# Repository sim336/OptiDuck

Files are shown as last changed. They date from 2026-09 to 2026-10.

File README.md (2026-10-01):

# OptiDuck

**一台用国产舵机复刻的 Microduck 双足机器人**：主控 Radxa ZERO 3W，执行器换成**飞特 HD-1910 总线舵机**，
步态策略在 MuJoCo / mjlab 里用 PPO 训练，导出 ONNX 后在板子上跑实时推理，
配套一套板端运维服务与 Android 远程运维 App。

这个仓库是**总入口**：它记录整条链路的文档、自研工具链、板端代码与训练侧改动，
上面三块上游代码以 git submodule 引入。

- [部署调试教程.md](docs/Radxa_ZERO_3W_部署调试教程_发布版.md)
- [开发教程.md](docs/Radxa_ZERO_3W_开发教程_发布版.md)

> 本项目是**个人学习 / 复刻项目**，不是产品。所有数据、命令、报错原文都来自这台实机，
> 能复现的写了复现方式，没验完的明确标了「待核实」。详见 [NOTICE.md](NOTICE.md)。

---

## 目录

- [它长什么样](#它长什么样)
- [系统架构](#系统架构)
- [仓库结构](#仓库结构)
- [快速开始](#快速开始)
- [自研工具链：URDF / MJCF 可视化](#自研工具链urdf--mjcf-可视化)
- [板端运维工具](#板端运维工具)
- [实测数据](#实测数据)
- [和上游的关系](#和上游的关系)
- [许可与署名](#许可与署名)
- [大体积数据](#大体积数据)
- [这个项目对应哪些能力](#这个项目对应哪些能力)
- [更新日志](#更新日志)

---

## 它长什么样

### 实机：整机装配完成（2026-10-01）

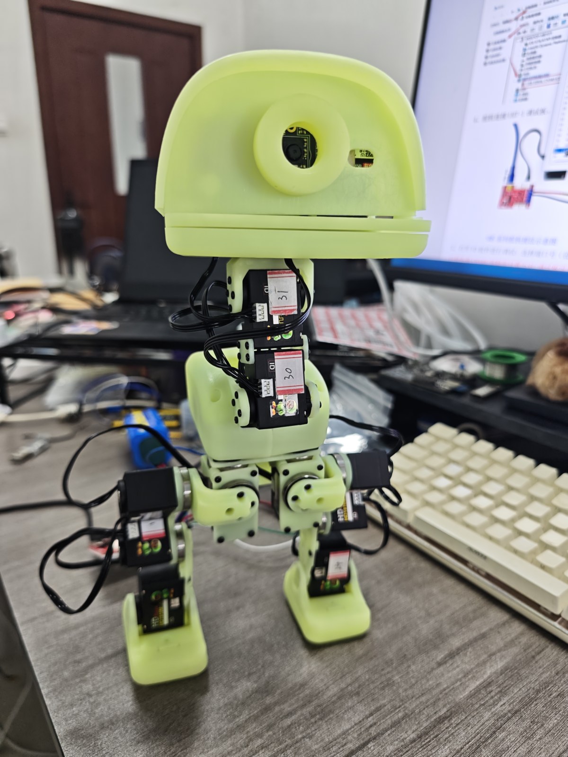
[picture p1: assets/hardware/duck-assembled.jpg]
实机装配完成


薄荷绿色的是打印结构件，黑色的是 15 颗飞特 HD-1910 总线舵机（机身上能看到手写的 ID 标签），
头部开了摄像头孔。装配已完成，能靠两条腿立在桌面上。
这一版还是**裸机状态**：躯干外壳没上、线束没整理，所以图里能看到成把的舵机线和裸露的板子。

### 实机跑策略：起身没站稳就切了走路（2026-10-01）

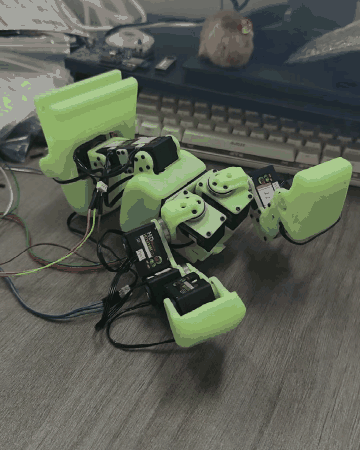
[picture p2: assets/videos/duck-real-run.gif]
实机运行策略


> 动图是 360 px 宽、6 fps 的压缩版；原片 720×1280 / 30 fps / 6.5 s 在
> [`assets/videos/duck-real-run.mp4`](assets/videos/duck-real-run.mp4)。

这是训练出的策略**第一次在真整机上闭环跑起来**的记录，实测结果如实记两条：

- **通过的**：策略确实在板上跑起来了，15 颗舵机按策略输出在动，不是静态摆拍。
- **没通过的**：跑了起身策略，但**没能站稳**，在抖动 / 翻倒的过程中就切去执行走路了 ——
  也就是「起身 → 稳定 → 走路」这三段的状态机衔接还不成立，所以画面里大部分时间
  是机器人在桌面上扑腾，而不是走出去。**这一条不记为「会走了」。**

待排查（都还没有验证，先记下来）：状态机从起身切到走路用的判据是什么（姿态角？计时？），
以及这块板子上当前加载的是哪一批权重。

### 板端：真实开发板上的状态看板

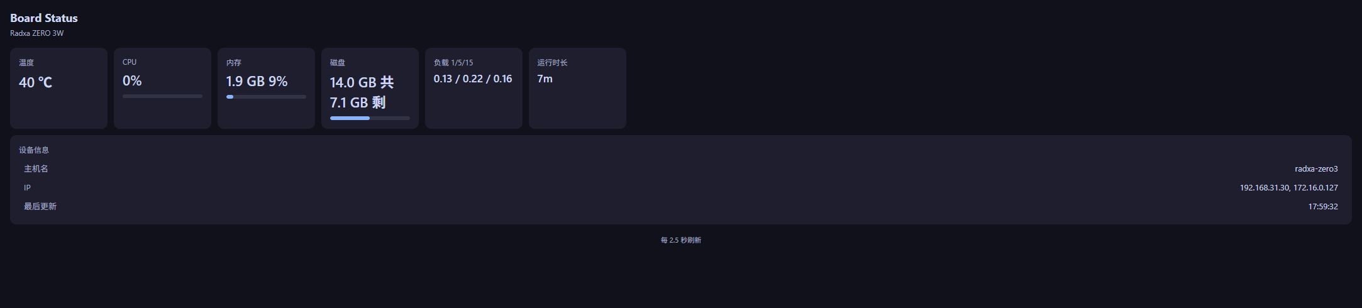
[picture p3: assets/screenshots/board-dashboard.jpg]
板端状态看板


Radxa ZERO 3W 上跑着自研的 Python 状态服务（systemd 托管，端口 8070），
每 2.5 秒刷新温度 / CPU / 内存 / 磁盘 / 负载 / 运行时长。
上图是**这台板子的真实截图**，不是设计稿。

### 训练侧：自研 URDF / MJCF 工具链

三个纯前端（three.js）工具，用来把 SolidWorks 模型转成 MuJoCo 能吃的 MJCF 并肉眼验证：

| 工具 | 干什么 | 截图 |
|---|---|---|
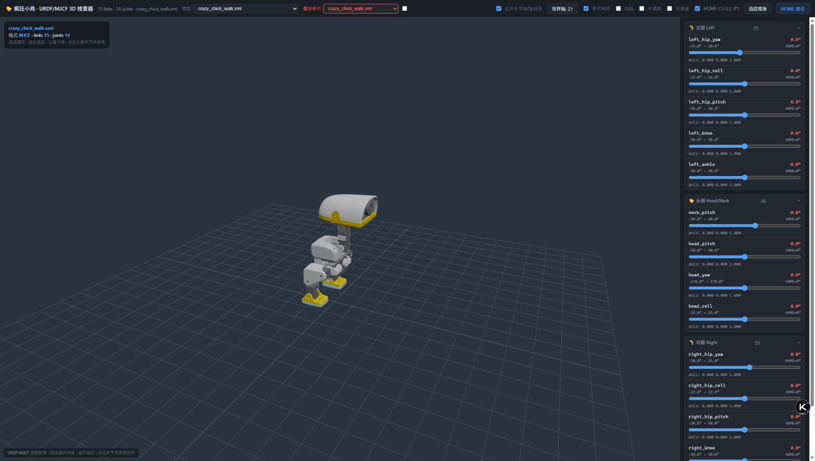
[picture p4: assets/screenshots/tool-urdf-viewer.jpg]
viewer
| **查看器** `viewer/` | 加载 MJCF，实时拖动每个关节的滑块，检查限位、碰撞、网格原点 |  |
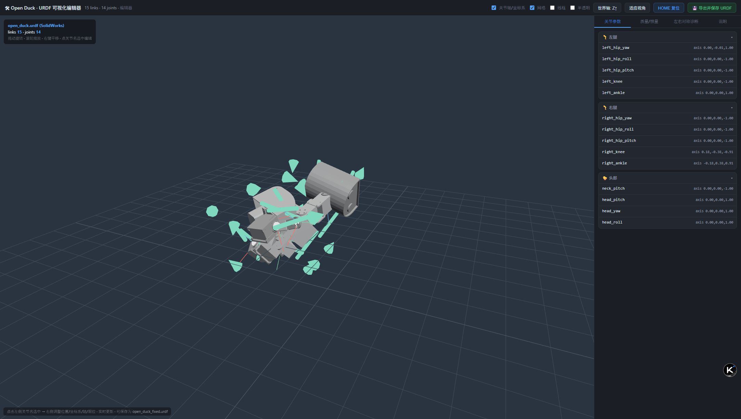
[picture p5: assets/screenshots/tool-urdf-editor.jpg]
editor
| **编辑器** `editor/` | 加载 URDF，改关节 origin / 轴 / 限位、link 质量惯量，左右腿对称诊断，导出修正后的 URDF |  |
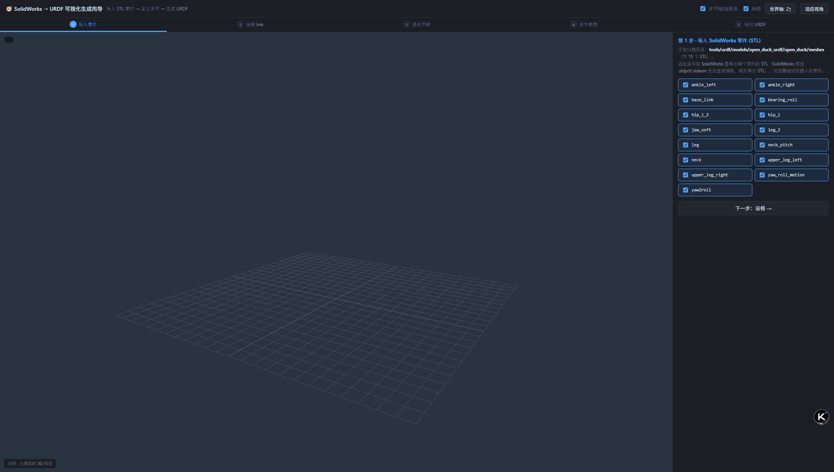
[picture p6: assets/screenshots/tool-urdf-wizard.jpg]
wizard
| **生成向导** `wizard/` | 扫描 STL 零件目录 → 勾选 → 自动生成 URDF 骨架 |  |

还有一个小工具 `mjcf-preview/`：只给 MJCF 的 14 个关节各一个滑块，快速看姿态对不对。

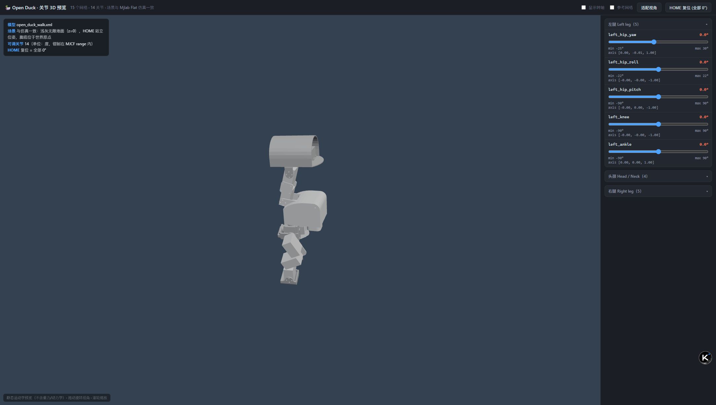
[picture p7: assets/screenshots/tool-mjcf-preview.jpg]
mjcf preview


### 仿真：策略 rollout 渲染帧

下面是 `training/` 里那段 rollout 的逐帧渲染（MuJoCo 离线出图，每 20 帧取一张）：

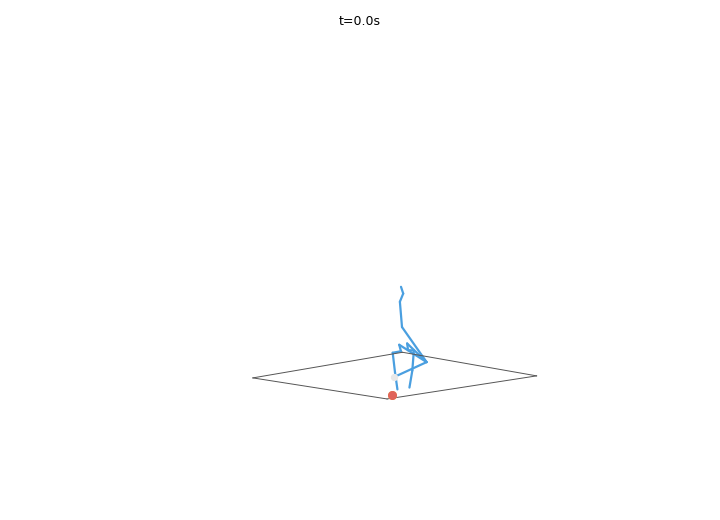
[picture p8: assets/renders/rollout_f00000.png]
rollout

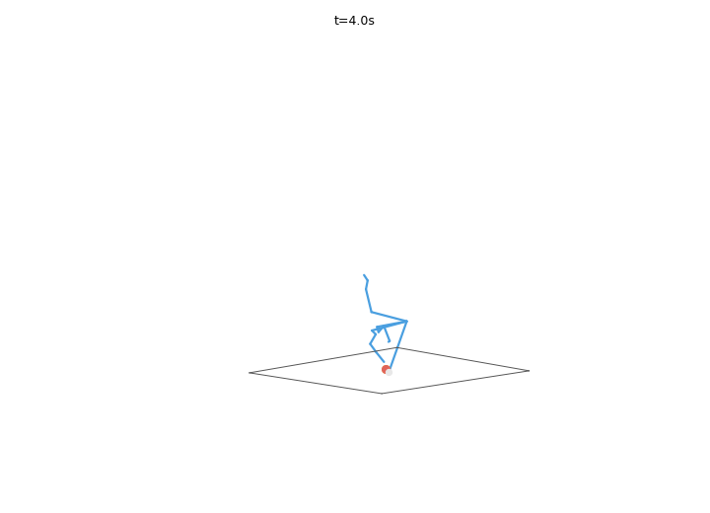
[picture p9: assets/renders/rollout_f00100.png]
rollout

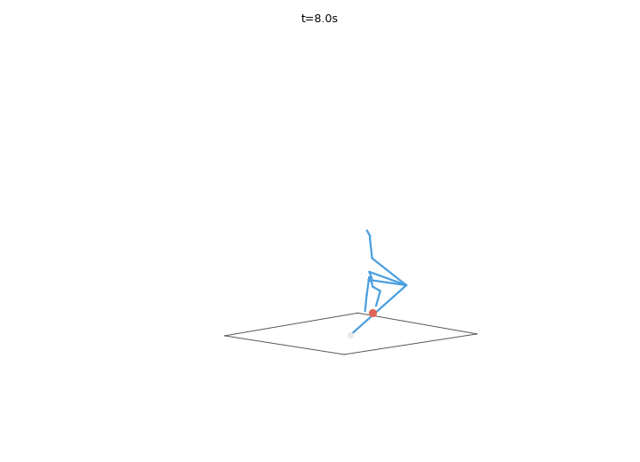
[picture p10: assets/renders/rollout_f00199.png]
rollout


### 移动端：Android 远程运维 App

Kotlin + Jetpack Compose 写的板端运维 App，底部五个页签 —— 连接 / 状态 / 画面 / 功能 / 终端，
支持远程状态告警、**板端摄像头实时画面（MJPEG）**、远程 shell（WebSocket + PTY，带 TAB 补全）与 APK 自更新。

下面四张是 **Android 模拟器里实际运行 App、并真的连上这块板子** 截的图：

| 连接 | 状态 |
|---|---|
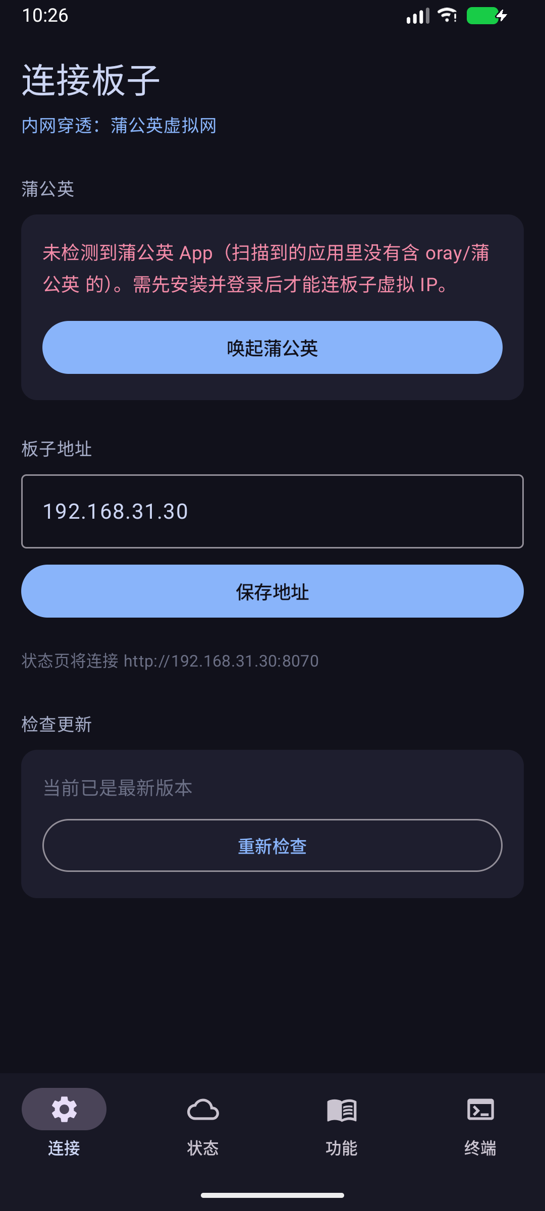
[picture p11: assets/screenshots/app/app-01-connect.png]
app-connect
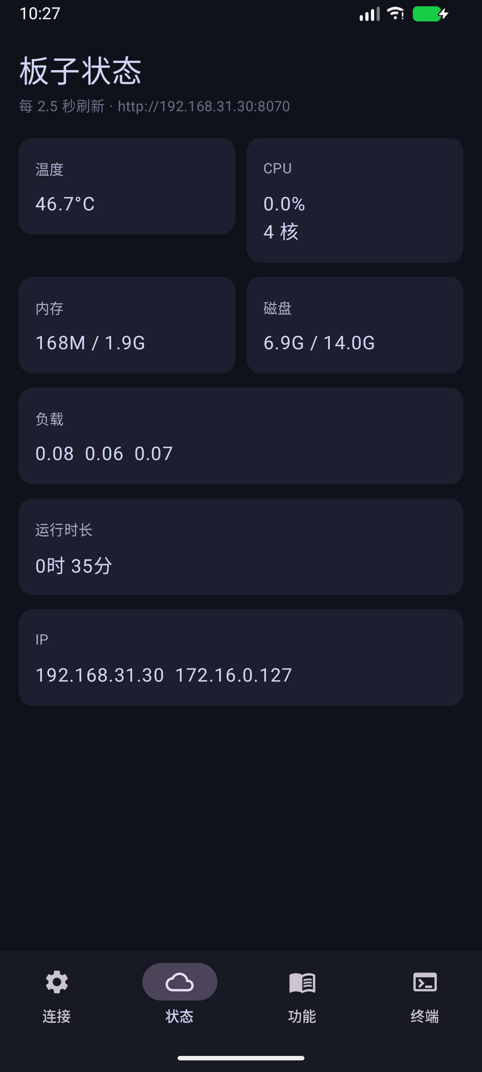
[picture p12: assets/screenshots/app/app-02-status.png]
app-status
|  |  |
| 板子地址、蒲公英检测、APK 自更新入口 | 实时读板上 8070 服务，2.5 s 刷新；图中的温度 / 负载 / IP 都是这台板子的真实值 |

| 功能 | 终端 |
|---|---|
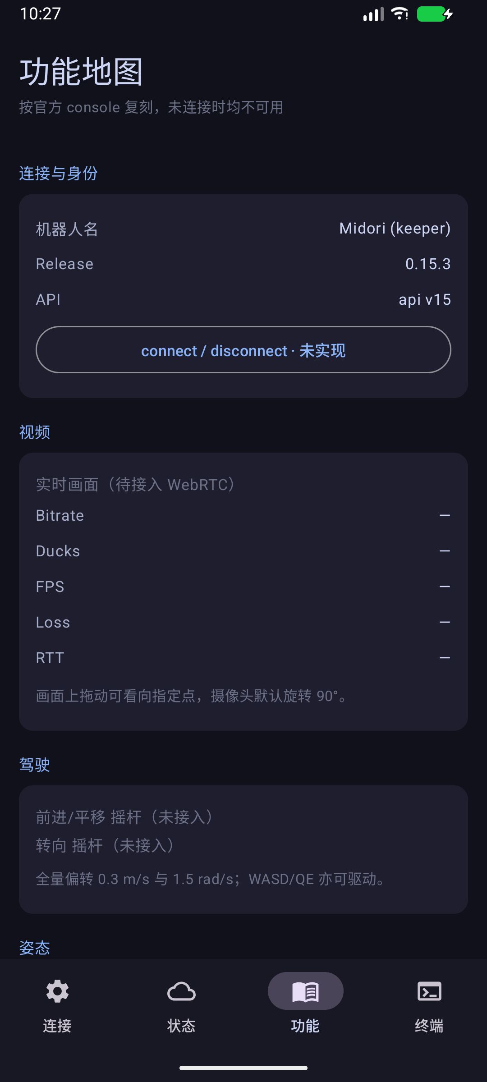
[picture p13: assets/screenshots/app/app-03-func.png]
app-func
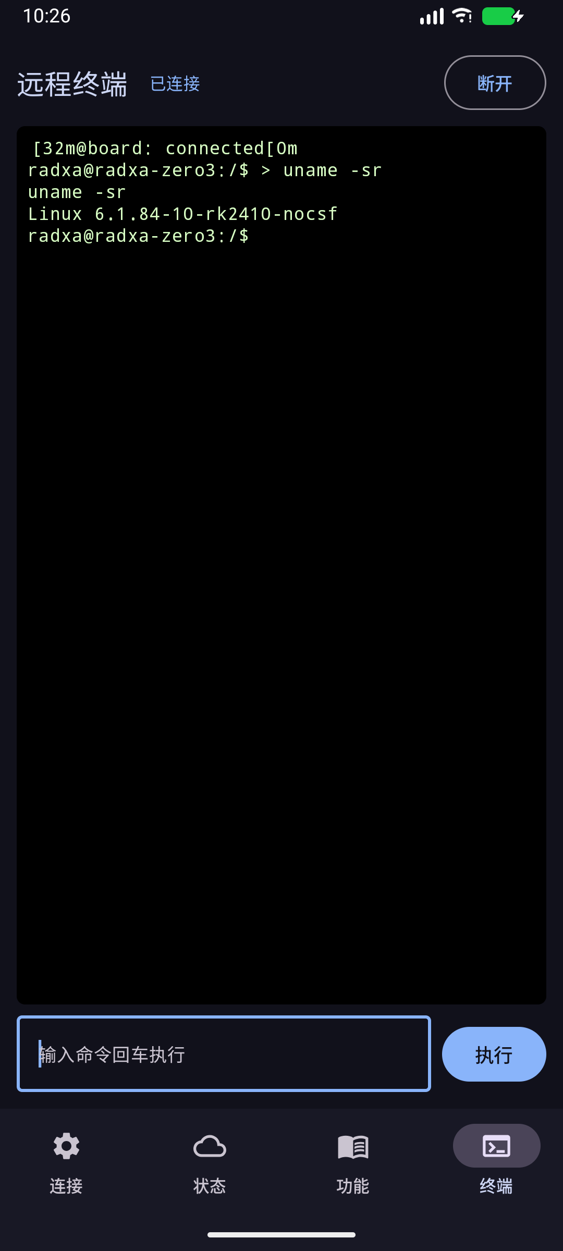
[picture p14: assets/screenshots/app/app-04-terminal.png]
app-terminal
|  |  |
| 按官方 console 复刻的功能地图，未接入的项标为「未实现 / 待接入」 | 远程 shell：首包带 token 鉴权，连上后 `uname -sr` 返回 `Linux 6.1.84-10-rk2410-nocsf` |

> 终端那张图里的输出是**真的从那块板子上取回**的，不是摆拍：
> App 先从 `/api/term` 拿 token，再带 token 连 8071 的 WebSocket，
> 板子侧为每个连接 spawn 一个 PTY bash。协议细节见 [board/report_terminal.py](board/report_terminal.py)。

---

## 系统架构

### 数据通路：仿真 → 板载

```mermaid
flowchart LR
    subgraph PC["开发机（Windows / Linux + CUDA）"]
        A["SolidWorks 整机模型"] --> B["SW2URDF<br/>导出 URDF"]
        B --> C["自研 URDF → MJCF 生成器<br/>重算质量 / 质心 / 惯量"]
        C --> D["MuJoCo 模型<br/>crazy_chick_*.xml"]
        D --> E["mjlab + PPO 训练<br/>走 / 起身 / 坐站"]
        E --> F["checkpoint"]
        F --> G["导出 ONNX"]
    end
    subgraph DEV["实机 / 台架"]
        G -->|"dev-push（交叉编译 + 签名）"| H["Radxa ZERO 3W<br/>robotd / updaterd"]
    end
    G -.->|"policy-rehearsal<br/>CPU 彩排 + 延迟体检"| PC
    H --> I["ONNX Runtime 推理<br/>50 Hz 控制环"]
    I --> J["15 颗 HD-1910 舵机<br/>UART2 总线"]
    I --> K["IMU（I2C4）"]
```

### 板端软件栈

```mermaid
flowchart TB
    subgraph BOARD["Radxa ZERO 3W · Radxa OS (Debian 12) · 6.1 内核"]
        R["robotd<br/>50 Hz 控制环 · 策略执行"] --- C["configd<br/>配置"]
        R --- U["updaterd<br/>OTA 升级 · 签名 · 回滚"]
        R --- BT["btd / padd / tofd<br/>蓝牙 / 触控 / ToF"]
        R --> BUS["舵机总线 /dev/ttyS2"]
        R --> IMU["IMU /dev/i2c-4"]
    end
    subgraph MINE["本项目自研（board/ + app/）"]
        S["robot_status.py<br/>状态服务 :8070"] 
        T["report_terminal.py<br/>WebSocket PTY 终端 :8071"]
    end
    APP["Android App<br/>com.optiduck.board"] -->|"HTTP /api/status"| S
    APP -->|"WebSocket + token"| T
    CLI["robotctl / duckctl"] --> R
```

> 控制环固定 **50 Hz**（20 ms 一拍）。7 个策略槽位名在 Rust 枚举里写死，不能增删改名，
> 只能指向不同的 ONNX 文件或置为 `none`。

---

## 仓库结构

| 路径 | 内容 | 来源 | 许可 |
|---|---|---|---|
| [`docs/`](docs/) | 两本实机教程（部署 / 开发）+ 内部草稿 | 自研 | Apache-2.0 |
| [`tools/`](tools/) | 自研工具链：`urdf/` 三个可视化工具（three.js 零依赖前端）+ 台架标定与遥测（`ft_regs.py` 舵机寄存器直读/直写、`servo_config_gui.py` 逐舵机配置、`bench_mirror.py` 台架实时镜像、`robotd_telemetry_bridge.py` 遥测转发） | 自研 | Apache-2.0 |
| [`board/`](board/) | 板端运维：状态服务、远程终端、画面流、systemd 单元、蒲公英组网脚本 | 自研 | Apache-2.0 |
| [`app/`](app/) | Android 运维 App（Kotlin + Compose） | 自研 | Apache-2.0 |
| [`imu2uart/`](imu2uart/) | STM32F411 固件：IMU → UART 桥（CubeMX 工程）。只入库自研源码与工程文件，vendor 库（`Drivers` 53 MB / `Middlewares`）与 Keil 编译产物可再生产 | 自研 | Apache-2.0 |
| [`training/`](training/) | 在上游 RL 仓里做的改动（补丁 + 改动后的文件） | 派生 | 见 NOTICE |
| [`assets/`](assets/) | 实拍素材与渲染出图：`hardware/` 实机照片、`videos/` 实机运行视频、`screenshots/` 真实截图、`renders/` 仿真渲染帧（**无 AI 生成图**） | 自研 | Apache-2.0 |
| `joyandai/microduck/` | 上板 Rust 软件栈（子模块） | 上游变体 | Apache-2.0 |
| `microduck_rl/` | RL 训练仓（子模块） | 上游变体 | Apache-2.0 |
| `OpenMicroDuck/` | 结构与硬件：CAD / BOM / 渲染图（子模块） | 上游 | **软件 Apache-2.0 / 硬件 CC-BY-NC-SA-4.0** |
| `_scratch_archive/` | 草稿归档：临时脚本、抓取日志、出图 | 自研 | — |

---

## 快速开始

### 一次拉全（含子模块）

```bash
git clone --recurse-submodules git@github.com:sim336/OptiDuck.git
cd OptiDuck
```

已经 clone 过、当时没带子模块：

```bash
git submodule update --init --recursive
```

### 三条链路从哪读起

**① 硬件 / 结构** —— 先看 `OpenMicroDuck/`

- 选型与零件清单：[OpenMicroDuck/docs/bom.md](OpenMicroDuck/docs/bom.md)、[structure.md](OpenMicroDuck/docs/structure.md)
- 舵机适配评审（为什么要换 HD-1910、装配冲突在哪）：[OpenMicroDuck/docs/servo.md](OpenMicroDuck/docs/servo.md)

> ⚠️ `OpenMicroDuck` 的 CAD 与图纸是 **CC-BY-NC-SA-4.0，不可商用**。
> 另有已知的 **BOM 数量分歧**（轴承 ET2216 的数量），下单前请看装配图确认，别直接照抄 BOM。

**② 训练** —— 看 [training/README.md](training/README.md)

它讲清了「哪些是上游的、哪些是我们改的」：新增的 `crazy_chick` MJCF 全套、
两个新任务（`Mjlab-Jump-Flat-CrazyChick` 62D/15D、`Mjlab-Velocity-Flat-OpenDuck` 61D/14D）、
以及为 12 V 供电补的舵机参数。改动以补丁形式给出，可以 `git apply` 回上游仓。

**③ 上板** —— 看两本教程

| 想做什么 | 看哪一节 |
|---|---|
| 先避坑（电源、烧录、Wi-Fi 自动连接） | 部署篇 §0 |
| 烧系统到 SD 卡 / SSH 免密 / headless | 部署篇 §4–§5 |
| 板级 bring-up（舵机总线 `ttyS2` / IMU `i2c4` / 依赖） | 部署篇 §6 |
| 装 `robotd` 等 daemon 软件栈 | 部署篇 §7 |
| 训练 → 导出 ONNX → CPU 彩排 → 发布上板 | 开发篇「模型链路」 |
| 舵机 / IMU / ToF / 摄像头排障 | 开发篇「硬件链路」 |
| 改 Rust 代码一分钟推到板子生效 | 开发篇「代码链路」（`dev-push`） |
| 自己发版 / 用开发签名 | 部署篇 §12 |

- [docs/Radxa_ZERO_3W_部署调试教程_发布版.md](docs/Radxa_ZERO_3W_部署调试教程_发布版.md)
- [docs/Radxa_ZERO_3W_开发教程_发布版.md](docs/Radxa_ZERO_3W_开发教程_发布版.md)

> `docs/internal/` 里是整理前的个人草稿，保留只是为了记录，别当成正式教程读。

**④ 移动端 App** —— 看 [`app/`](app/)

Kotlin + Jetpack Compose，Android Gradle 工程。仓库里**不带** Gradle Wrapper 和 JDK，
用你自己的环境编译即可：

```bash
cd app
# app/local.properties 里写好 sdk.dir=<你的 Android SDK 路径>
gradle assembleDebug          # 产物：app/app/build/outputs/apk/debug/app-debug.apk
adb install -r app/app/build/outputs/apk/debug/app-debug.apk
```

装好后在「连接」页把**板子地址**填成板子的 IP（默认填的是蒲公英虚拟 IP `172.16.0.127`），
状态页就会去读 `<地址>:8070/api/status`，终端页会去 `<地址>:8071` 建 WebSocket。

> ⚠️ Gradle 工程目录是 `app/`，里面的模块目录**也叫** `app/`，所以产物路径是 `app/app/build/...`，
> 不是 `app/build/...`。别找错。

---

## 自研工具链：URDF / MJCF 可视化

三个工具都是**纯前端**（three.js 本地 vendor，无 npm 依赖），靠一个 40 行的 `serve.mjs` 提供静态服务 + 一个保存端点。

### 跑起来

```bash
# 在仓库根目录
node tools/urdf/serve.mjs 8124 .
```

然后打开：

| 地址 | 工具 |
|---|---|
| `http://127.0.0.1:8124/tools/urdf/viewer/` | MJCF 关节查看器 |
| `http://127.0.0.1:8124/tools/urdf/editor/` | URDF 编辑器 |
| `http://127.0.0.1:8124/tools/urdf/wizard/` | SolidWorks → URDF 生成向导 |
| `http://127.0.0.1:8124/tools/urdf/mjcf-preview/` | 14 关节姿态预览 |

> **注意第二个参数**：`serve.mjs` 的根目录必须是**仓库根**，不能是 `tools/urdf/`。
> 因为 viewer 的模型路径写的是仓库内路径（`/microduck_rl/...`、`/training/...`），
> 根目录设错会全部 404。

### 为什么要有这套东西

从 SolidWorks 导出的 URDF 到 MuJoCo 能跑的 MJCF，中间有几件必须肉眼确认的事：

1. **网格原点对不对** —— STL 的原点不在关节轴上，模型就会飞。viewer 拖动关节滑块能立刻看出来。
2. **关节轴向对不对** —— 轴反了，仿真里腿会朝反方向弯。
3. **质量和惯量是不是瞎填的** —— SW2URDF 出来的惯量经常是占位值，要重算。
4. **左右腿是不是对称** —— editor 里有专门的对称诊断。

`wizard/` 解决的是第 1 步之前的脏活：SolidWorks 一次导出几十个 STL，
文件名毫无规律，手工写 URDF 的 `<link>`/`<joint>` 又慢又容易漏。

---

## 板端运维工具

`board/` 里是这台板子上**实际在跑**的东西（不是示例代码）。

| 文件 | 作用 | 板上位置 |
|---|---|---|
| `robot_status.py` | 健康指标 HTTP 服务（端口 8070，返回 `/api/status` JSON） | `/home/radxa/robot_status.py` |
| `index.html` | 状态看板的单页前端（深色卡片，2.5 s 轮询） | `/home/radxa/robot_status_index.html` |
| `report_terminal.py` | WebSocket 远程终端（端口 8071，每次连接 spawn 一个 PTY bash，支持 TAB 补全与颜色） | `/home/radxa/report_terminal.py` |
| `report_video.py` | 摄像头 MJPEG 服务（端口 8072，`/video` 长连接推 640×480@15 的 JPEG；懒启动，无客户端 5 s 自动停流水线，**不经过 mediad**；`/dev/video0` 独占，不能与 mediad 并存） | `/home/radxa/report_video.py` |
| `robot_terminal.py` | 终端侧的辅助脚本 | `/home/radxa/robot_terminal.py` |
| `systemd/robot-status.service` | 状态服务的 systemd 单元 | `/etc/systemd/system/` |
| `systemd/robot-terminal.service` | 终端服务的 systemd 单元 | `/etc/systemd/system/` |
| `systemd/robot-video.service` | 画面服务的 systemd 单元 | `/etc/systemd/system/` |
| `scripts/deploy_status.sh` | 一键部署状态服务到板子 | — |
| `scripts/deploy_video.sh` | 一键部署画面服务到板子（含出流自检） | — |
| `scripts/diag_sudo.sh` | 提权环境诊断 | — |
| `scripts/pgy_*.sh` | 蒲公英（异地组网）客户端的安装 / 登录 / 状态脚本 | — |

### 终端鉴权

终端服务**不能裸露**：每个连接的首包必须带上 token，
token 由板子生成在 `/home/radxa/robot_terminal_token`，
App 先从状态服务的 `/api/term` 拿到端口与 token 再去连。

> ⚠️ **不要把 8071 / 8443 这类端口直接转发到公网。** 这是明确的部署禁忌：
> 一旦暴露，等于把一台能跑 `sudo` 的 shell 送出去。

### 板子上的实况

```
$ robotctl health
robot     degraded: no robot on the motor bus after 99 attempts; is servo power on and the bus wired?
  loop      not measured yet, of 50.0 Hz · 0 ticks · 0 missed
  bus       waiting for a robot to answer, 99 attempts
  imu       not ready

software
  updaterd  0.13.0 (rev 84684db)     units
  robotd    0.13.0 (rev 84684db)       updaterd  active · 0.13.0
  configd   0.13.0 (rev 84684db)       robotd    active · 0.13.0
                                       configd   active · 0.13.0
                                       btd       active · 0.13.0
                                       padd      active · 0.13.0
                                       mediad    stopped
                                       tofd      active · 0.13.0
```

这段是**当前这台板子的真实输出**（照抄，未修饰）。`degraded` 是因为舵机电源此刻没开 ——
`robotd` 上电后要先在总线上找到机器人，找不到就一直重试，这是正常且安全的行为。
`mediad` 是 stopped：**没接摄像头时它会崩溃循环**（找不到 `/dev/media*` 就退出，
systemd 每 ~12 s 拉起一次，每次重扫 GStreamer 插件烧满一核），所以按需再启用。

策略槽位的实况：

```
$ robotctl policy list
mode: walk

   SLOT         ORIGIN     POLICY
   walk         official   velstand.onnx
 * stand        local      /home/radxa/standup_hd1910.onnx
   sitstand     official   alpha_sitstand.onnx
   ground_pick  official   alpha_ground_pick.onnx
   kick_left    official   ball_kick_left.onnx
   kick_right   official   ball_kick_right.onnx
   roulade      official   roulade.onnx
```

`stand` 槽位指向的是**我们自己重训的 HD-1910 起身策略**，其余仍是官方策略。

---

## 实测数据

### 板载 ONNX 推理延迟

在**这台 Radxa ZERO 3W 上**用仓库里编译好的 `policy-rehearsal`（`joyandai/microduck` 的
`duck-control/examples/policy-rehearsal.rs`）跑 1000 步纯推理：

```bash
export ORT_DYLIB_PATH=/usr/local/lib/libonnxruntime.so
./target/release/examples/policy-rehearsal /home/radxa/standup_hd1910.onnx
```

```json
"latency_ms": { "p50": 0.367204, "p95": 0.76124, "p99": 0.836198, "max": 1.069237 },
"over_20_ms": 0,
"scope": "actor inference only; excludes sensor and motor I/O",
"steps": 1000
```

- **p50 ≈ 0.37 ms**，占 50 Hz 控制周期（20 ms）的 **约 1.8%**，p99 也只有 0.84 ms。
- **`over_20_ms: 0`** —— 1000 步里没有一次推理超出控制周期。
- ⚠️ 注意 `scope`：**这只统计 actor 网络推理**，不含读传感器和写舵机的时间。
  拿这个数去论证「整个控制环能跑满 50 Hz」是不严谨的。

### 板子本身

| 项 | 值 |
|---|---|
| 主控 | Radxa ZERO 3W（RK3566 · 2 GB LPDDR4） |
| 系统 | Radxa OS（Debian 12 bookworm），内核 `6.1.84-10-rk2410-nocsf` |
| 舵机 | 飞特 HD-1910-C001 × 15，总线 `/dev/ttyS2`（UART2） |
| 舵机 ID | 左腿 20–24、右腿 10–14、头/颈/嘴 30–34、IMU 200 |
| IMU | I²C-4 |
| 摄像头 | IMX219 8 MP（3280×2464，77° 裸模组） |
| 推理库 | ONNX Runtime 1.28.0（`/usr/local/lib/libonnxruntime.so`） |

> 以上是**逐项 SSH 实测核对过**的值；与网上流传的二手资料不一致的地方（例如
> 舵机总线实测是 I²C4 而某些文档写 I²C3 M0、摄像头 overlay 的启用方式）
> 均已按实机修正，教程里标注了核实状态。

---

## 和上游的关系

`joyandai/microduck` 和 `microduck_rl` **不是干净的上游副本**，而是带本地改动的变体。
为了让以后的合并干净可查，它们都被重新挂到上游历史里最接近的 commit 上，
本地改动各自落成一个独立 commit：

- `joyandai/microduck`：基线 `2c61dcc`（上游 2026-09-02），本地变体 commit `83322b6`
  —— HD-1910 台架 bring-up、IMU 迁到 I2C、舵机总线工具、`source-lessons/` 等 57 个文件。
- `microduck_rl`：上游分支 `develop`，本地改动为 HD-1910 台架 bring-up、BAM 作动器参数、
  `air_time` 奖励调参与碰撞配置拆分；另含 Windows 下的彩排控制改造
  （`infer_policy.py` 用 `msvcrt` 替代 Unix 专属的 `termios`，让彩排能在开发机上直接跑）。
  2026-10-01 又落了 3 个提交：① 供电基准更正到整机 2S（`vin_range` 6.5–8.2、`vin_min` 6.0、
  `forcerange` 0.97 → 1.51 N·m），并补齐 `GROUND_PICK` / `BACKLASH` / `WALK_BACKLASH` 三处
  漏掉的 `USE_HD1910` 判断（含两个新导出的 `robot_openmicroduck_*_backlash.xml`）；
  ② `scene.xml` / `body_server.py` 改指向 OpenMicroDuck 鸭子（此前仿真身体与训练环境不是同一只）；
  ③ velstand 把零指令站立提为一等交付。详见更新日志 v1.02 / v1.03。

这样 `git log` 能直接看出「哪些是上游的、哪些是我们改的」，
`git diff upstream/main` 就是全部本地差异。

### 改动怎么同步（子模块的两步法）

三个代码仓是**独立仓库**，各自提交推送；主仓只记录「指向哪个 commit」。所以一次改动要两步：

```bash
# 第 1 步：在子仓里改、提交、推送
cd microduck_rl
git add -A && git commit -m "..." && git push

# 第 2 步：回主仓更新指针（不能省）
cd ..
git add microduck_rl
git commit -m "bump microduck_rl"
git push
```

第 2 步不能省：别人 clone 主仓时拿到的是主仓里记录的 commit，
你不提交指针，别人就还停在你上次提交的那个版本。

### 合并上游更新

```bash
cd joyandai/microduck
git fetch upstream
git merge upstream/main
```

`microduck_rl` 的上游默认分支是 `develop`。

---

## 许可与署名

| 部分 | 许可 |
|---|---|
| 本仓自有内容（`docs/`、`tools/`、`board/`、`app/`、`imu2uart/`、`assets/`） | **Apache-2.0**（[LICENSE](LICENSE)） |
| `joyandai/microduck`、`microduck_rl` | Apache-2.0 |
| `OpenMicroDuck` 的 CAD / 图纸 / 文档 | **CC-BY-NC-SA-4.0（禁止商用）** |

**完整的分项署名、上游链接与免责声明见 [NOTICE.md](NOTICE.md)。**
商业使用前请务必读一遍 —— `OpenMicroDuck` 那一块是不可商用的。

`assets/` 里**没有任何 AI 生成图片**：`hardware/` 的实机照片与 `videos/` 的运行视频是手机实拍，
`screenshots/` 来自真实浏览器 / Android 模拟器 / 这块开发板，`renders/` 来自 MuJoCo 离线出图。

---

## 大体积数据

以下数据**不在 git 里**（避免仓库膨胀且历史不可撤销），按需作为 Release 附件发布：

| 数据 | 体积 | 说明 |
|---|---|---|
| `hd1910_calibration/` | ~426 MB | HD-1910 舵机台架标定原始 `.log` 轨迹与拟合 `.json` |
| `model_archive/` | ~405 MB | 训练权重归档（sitstand / stand / velocity） |
| `logs/` | ~8 MB | 台架 / 分析 / sysid 原始数据（`bench_*.csv`、`analysis_*.csv`、`sysid_*.md`）。本机工作数据，已加进 `.gitignore`，不作为 Release 附件 |

标定数据拟合后的结果已经浓缩进 `microduck_rl/vendor/bam/bam/params/hd1910/*.json`，
只做仿真训练的话不需要下载原始数据。

---

## 这个项目对应哪些能力

把简历上的项目二拆开到具体产物，方便对照：

| 能力点 | 在本仓的产物 |
|---|---|
| 执行器建模：基于 HD-1910 重绘整机三维模型（SolidWorks） | `OpenMicroDuck/`（CAD / BOM / 结构评审） |
| SW2URDF 导出 + **自研 URDF→MJCF 生成器** | [`tools/urdf/wizard/`](tools/urdf/wizard/)（零件扫描 → URDF）、[`training/microduck_rl/.../crazy_chick/`](training/microduck_rl/src/mjlab_microduck/robot/crazy_chick/)（`make_crazy_chick.py` / `make_open_duck.py`） |
| 重算刚体质量与质心、构建 MuJoCo 仿真模型 | 同上 + [`tools/urdf/viewer/`](tools/urdf/viewer/) 肉眼校验 |
| RL 步态训练（PPO：行走 / 起身 / 坐站） | [`training/README.md`](training/README.md) + `microduck_rl/` 子模块 |
| 针对新舵机增益差异调超参、BAM 作动器辨识 | `microduck_rl/vendor/bam/`、`training/microduck_rl/patches/` |
| Windows 下彩排环境控制（msvcrt 替代 termios） | `microduck_rl/scripts/infer_policy.py` |
| Radxa ZERO 3W 从烧录到 headless 全流程 | [部署调试教程](docs/Radxa_ZERO_3W_部署调试教程_发布版.md) |
| Microduck OTA 升级通道部署与配置 | [开发教程](docs/Radxa_ZERO_3W_开发教程_发布版.md)「代码链路」+ `joyandai/microduck` 的 `updaterd` |
| ONNX 导出 + 板端 ONNX Runtime 推理链路 | [实测数据](#实测数据) 一节（含可复现命令） |
| Python 板端状态服务 + WebSocket 远程终端 | [`board/robot_status.py`](board/robot_status.py)、[`board/report_terminal.py`](board/report_terminal.py) |
| Kotlin/Compose Android App：状态告警 / 远程 shell / APK 自更新 | [`app/`](app/) |
| 跨平台嵌入式开发（C/C++、Python、C#、Kotlin、Rust 周边） | 全仓 |
| ROS / MuJoCo / MATLAB 轨迹规划等工具链经验 | `tools/`（自研可视化）、`microduck_rl`（mjlab + MuJoCo） |

---

## 更新日志

| 版本 | 日期 | 内容 |
|---|---|---|
| **v1.04** | 2026-10-01 | **整机装配完成，策略第一次在真机上跑（附实拍素材）**。<br>① 新增 [`assets/hardware/duck-assembled.jpg`](assets/hardware/duck-assembled.jpg)：15 颗 HD-1910 装到位的整机外观照 —— 打印结构件 + 黑舵机 + 头部摄像头孔，**裸机状态**（躯干外壳未上、线束未整理）。<br>② 新增 [`assets/videos/duck-real-run.gif`](assets/videos/duck-real-run.gif)（README 内嵌动图，360 px / 6 fps / 2.6 MB）与 [`assets/videos/duck-real-run.mp4`](assets/videos/duck-real-run.mp4)（原片 720×1280 / 30 fps / 6.5 s / 0.94 MB）：训练策略第一次在**真整机**上闭环跑的实拍。<br>③ **实测结论 —— 通过项**：策略确实在板上跑起来了，15 颗舵机按策略输出动作。<br>④ **实测结论 —— 未通过项（如实记录，不记为「会走了」）**：跑的是起身策略，但**没站稳**，在抖动 / 翻倒过程中就切去执行走路了 —— 「起身 → 稳定 → 走路」三段的状态机衔接不成立，画面里大部分时间是机器人在桌面上扑腾。<br>⑤ **待排查（均未验证，先留档）**：状态机从起身切到走路的判据是什么（姿态角？计时？）；这块板子上当前加载的是哪一批权重（与 [v1.02](#更新日志) 的供电基准更正 / 仿真·真机饱和率失配是否相关，也还没有证据）。 |
| **v1.03** | 2026-10-01 | **台架工具链、IMU 固件入库，以及 docs 的摄像头记录**。<br>① `tools/` 新增 6 个台架工具（都不是示例代码，是台架上实际在用的）：`ft_regs.py` —— FT-SCS 寄存器直读/直写，起因是 `robot.relax` 报 `torque off`、15 颗舵机全部 ACK 但关节掰不动，绕开 robotd 直读总线后发现 15 颗的 reg40 实测全是 1，那条「已松扭矩」的结论是假的；`servo_config_gui.py` + `servo_progress.json` 逐舵机配置与进度；`bench_mirror.py` 台架只读实时镜像（真机 15 颗 HD-1910 + IMU 映到浏览器 3D，带策略开关与「真·松扭矩」联调按钮）；`robotd_telemetry_bridge.py` 遥测转发；`bench_joint_limits.json` 实测关节限位。<br>② 新增 [`imu2uart/`](imu2uart/) —— STM32F411 的 CubeMX 固件（IMU → UART 桥）。**只收自研源码与工程文件**（`Core/` + `.ioc` + `.mxproject` + Keil 的 `.uvprojx`/`.uvoptx`/`startup`，约 0.2 MB），vendor 库（`Drivers` 53 MB、`Middlewares` 1.3 MB）与 Keil 编译产物（38 MB，另有 7.2 MB `JLinkLog`）全部排除，可由 CubeMX / Keil 再生。<br>③ `logs/` 台架原始数据按仓库既有约定「大体积数据走 Release、不进 git 历史」加入 `.gitignore`。<br>④ `docs/internal` 的零基础教程把摄像头一节从【等硬件】改为【现在能跑】：2026-09-22 已在本机点亮 IMX219（overlay 启用后 probe 成功、`/dev/media0` + `/dev/video0~9` 就位、连续抓流 45 帧 @ 29.96 fps），并更正三处易踩的点 —— Radxa OS 上不用手工编辑 `extlinux.conf`（`u-boot-update` 会把 `/boot/dtbo/` 下所有不带 `.disabled` 的 `.dtbo` 按字母序写进 `fdtoverlays`）；`/boot/dtbo/` 下其实有三个 camera overlay（两个 IMX219 驱动层等价）；别只靠 `dmesg` 验证 —— 它要 sudo，且只证明 sensor probe 成功、不证明链路连通。<br>⑤ `microduck_rl` 另外两个提交：`scene.xml` / `body_server.py` 改指向 OpenMicroDuck 鸭子（此前仿真身体与训练环境不是同一只），velstand 把零指令站立从 25% 侧例提到一等交付（板子上 `stand = "none"`，走路网络是零指令待机的唯一归属者）。 |
| **v1.02** | 2026-10-01 | **训练侧 HD-1910 一致性与供电基准核查（一轮完整审计的落地）**。<br>① **供电基准更正**：训练配置曾按 "5.0 V 稳压轨（4.75–5.25 V）—— NOT 2S" 建模，那个 5 V 是**摆锤台架的桌面电源**，不是整机。整机是 2S 电池、15 个舵机直接挂在电池上（证据：舵机是 4–8.4 V 器件；`duck-control/src/feetech.rs` 写明 "all 15 servos sit on one pack"；robotd 空电关机阈值 6.6 V，若真是 5 V 每次上电都会关机而它从未触发）。改为 `vin_range=(6.5, 8.2)`、`vin_min=6.0`（`microduck_constants.py`）。模型的出力是 `vin × duty_cycle`，所以 5 V 基准会让仿真舵机比真机**弱 1.48 倍**（7.4/5.0）—— 这正是长期存在的仿真/真机饱和率失配（仿真 21% vs 真机 4.2%）的方向与量级；出力由 0.97 N·m 提到 **1.51 N·m**。<br>② **补齐三处漏改**（此前"换执行器只改一处"的说法是错的）：`MICRODUCK_GROUND_PICK_ROBOT_CFG` 与两个 backlash 配置漏了 `USE_HD1910` 判断，会用**官方 XL330 惯量 + HD-1910 执行器参数**的混搭模型；另新导出 `robot_openmicroduck_{walk,groundcontact}_backlash.xml`（`add_backlash.py` 默认 ±1° 背隙，14 个关节，与官方版结构逐项一致、总质量 812.61 g vs 官方 737.24 g）。rollers 两个配置仍为**已知缺口**，原因写在 `microduck_constants.py` 注释里（OpenMicroDuck 没有带轮子的 CAD 导出）。`publish/manifest.py` 的 `robot.servos` 由 `xl330` 更正为 `hd1910`（该字段在 `docs/policy-manifest.md` 里属 display 字段，daemon 只校验 `robot.model`）。<br>③ **参数归属澄清**：`kt = 0.692 N·m/A` 是**台架空载恒速法实测**（R²=0.998，n=24，6 档转速正反两向各两条），不是规格书值；规格书 0.7358 高约 6%，被独立方法（静态保持法 `kt/R ∈ [0.16, 0.23]`）交叉验证。`kp_fw = 32` 是**真机 reg50 回读**（不是 XL330 的 200，用 200 会硬约 6 倍）。<br>④ **文档更正**：`hd1910_README.md` 全文停留在标定前（描述 `hd1910_m6.json`、kp_fw 200、max_current 1.75、复用 xl330 骨架），已加"已过时"标注 + 估算值/现行值对照表，并保留仍然有效的规格书推导；`mae_report_kpfix.md` 标注为已过时的中间快照（权威记录是 `characterization.json`）；`characterization.json` 的 `supply_voltage_V: 5.0` 与 `note_supply` 标注作废（**数值一字未改**）。<br>⑤ **新增一个已知的显示级不一致**（未改，留档）：`bam/feetech/actuator.py` 的便捷属性 `self.kt = 0.7358` 是规格书默认值，而生效值是模型 JSON 覆盖后的 `model.kt = 0.692`——控制律用的始终是后者，故不影响物理，只可能误导日志读数；`kd` 的 sim 0.346（拟合，`d_scale=4.0`）与真机 reg51 的寄存器值 40 不是同一单位，勿直接对比。 |
| **v1.01** | 2026-09-22 | **App 打通实时画面（自建 MJPEG，全程不经 mediad）**。① 板端新增 [`board/report_video.py`](board/report_video.py)：GStreamer `v4l2src ! videorate ! videoconvert ! jpegenc ! appsink` 直接抓 `/dev/video0`，以 `multipart/x-mixed-replace` 推流（端口 8072），首包带 token（复用 `/home/radxa/robot_terminal_token`），流水线**懒启动、无客户端 5 s 自动停**，另有 `/snapshot` 单帧与 `/stats` 自检端点；② App 底部导航扩为 **5 个页签**（连接 / 状态 / 画面 / 功能 / 终端，App 版本 2.1.0 → 2.2.0、versionCode 5），新增 [`VideoScreen.kt`](app/app/src/main/java/com/optiduck/board/VideoScreen.kt) 按 SOI/EOI 切帧、逐帧解码上屏，并显示分辨率 / 帧率 / 累计帧 / 单帧大小；功能地图的「视频」区块从占位改为跳转「画面」页，WebRTC 那套指标（bitrate / loss / RTT）明确标注仍未接入；③ **实测**（板子本机 curl 拉流）：4 s 收 **58 帧 ≈ 14.5 fps**、单帧 ≈ **20 KB**（约 2.3 Mbps）、`/snapshot` 落盘为合规 640×480 baseline JPEG 且画面可辨实物（天花板灯管 + 纸箱），无 token 一律 401、无客户端 5 s 后 `/stats` 回到 `running: false`；④ **CPU 实测**（占单核）：无客户端、流水线已停时 **0.0%**，1 个客户端推 640×480@15 时 **≈16%**（≈ 整机 4%），推流期间板子 loadavg 0.11 → 0.51、温度 50.6 → 51.2 °C 基本不动 —— 所以**「连接 / 断开」本身就是开关，默认关，不连时板上零占用**，未再加额外总闸；⑤ 两个坑：PyGObject **不暴露** `GstAppSink.pull_sample` / `try_pull_sample`（GIR 注记把它们隐藏了），只能用 `new-sample` 信号 + `sink.emit("pull-sample")` 取帧；**`/dev/video0` 是独占设备**，第二个抓流进程直接报 `Device '/dev/video0' is busy`，即本服务与官方 mediad / WebRTC **互斥不能并存**。 |
| **v1.00** | 2026-09-19 | 仓库整体整理为开源项目形态：<br>① 目录重构 —— 教程归 `docs/`、URDF 工具链归 `tools/`、板端运维归 `board/`、Android App 归 `app/`、训练改动归 `training/`、截图与渲染归 `assets/`；<br>② 补齐 `LICENSE`（Apache-2.0）、`NOTICE.md`（分项署名与上游许可）、`.gitignore`；<br>③ 新增真实截图墙（板端看板 / 三个 URDF 工具 / MJCF 预览 / App 四页，均为实际运行截图）；<br>④ 修复状态看板「磁盘」卡片把字节数直接显示的 bug（改为 `xx.x GB 共 xx.x GB 剩`）；<br>⑤ 修复搬迁后工具链的模型路径（viewer / editor / wizard 全部指向仓内路径），并把 `serve.mjs` 的根目录用法写进文档；<br>⑥ 实测并记录板载 ONNX 推理延迟（p50 0.367 ms / 1000 步 / `over_20_ms: 0`）；<br>⑦ App 端到端联调：重新编译 debug APK 装进模拟器，实测「状态页读到板上真实指标 + 终端 WebSocket 带 token 连上并执行 `uname -sr`」，截图与结论一并入库。 |

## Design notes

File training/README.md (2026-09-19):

# training/ · 强化学习训练侧的改动

这里放的是**在别人开源仓库里做的改动**（补丁 + 改动后的文件），用于溯源：
哪些是上游的，哪些是本项目自己加的。

训练本身需要在装了 CUDA 的机器上跑 mjlab + MuJoCo，本目录**不是可直接运行的训练仓**，
它是「改动集」——把它应用回上游仓才能跑。

---

## 一、两个上游仓与本地改动

| 子目录 | 上游仓库 | 本地改动性质 |
|---|---|---|
| `microduck_rl/` | [pollen-robotics/microduck_rl](https://github.com/pollen-robotics/microduck_rl)（`develop` 分支） | 4 个官方文件被改写 + 一套新增的 `crazy_chick` 模型与任务 |
| `Open_Duck_Playground/` | [apirrone/Open_Duck_Playground](https://github.com/apirrone/Open_Duck_Playground)（`main` 分支） | 1 处：给 MJCF 补 `sts3215_12v` 执行器类 |

---

## 二、目录结构

```
training/
├── microduck_rl/
│   ├── patches/
│   │   └── tracked_changes.patch            ← 4 个官方文件的 diff，可直接 git apply
│   ├── scripts/                             ← 新增：冒烟 / 渲染 / 实时可视化脚本
│   │   ├── live_open_duck.py
│   │   ├── render_open_duck_rollout.py
│   │   ├── smoke_crazy_chick.py
│   │   └── smoke_open_duck.py
│   ├── src/mjlab_microduck/
│   │   ├── actuator/friction_dr_bam.py      ← 修改版
│   │   ├── robot/crazy_chick/               ← ★ 自研：MJCF / 常量 / 生成器 / 网格
│   │   │   ├── crazy_chick_*.xml            （walk / allcollisions / 各 backlash 变体）
│   │   │   ├── open_duck_walk.xml           （SolidWorks 形态）
│   │   │   ├── make_crazy_chick.py / make_open_duck.py
│   │   │   ├── assets/params_sts3215_m6.json
│   │   │   └── open_duck_assets/*.STL
│   │   └── tasks/
│   │       ├── microduck_jump_env_cfg.py        ← ★ 新增任务（62D 观测 / 15D 动作）
│   │       ├── microduck_open_duck_env_cfg.py   ← ★ 新增任务（61D / 14D，velocity）
│   │       ├── microduck_roller_standup_env_cfg.py  ← 修改版（关节索引修正）
│   │       └── __init__.py                      ← 修改版（注册新任务）
│   └── tests/test_roller_standup_cfg.py     ← 修改版（配套索引测试）
│
└── Open_Duck_Playground/
    ├── patches/0001-12v-parameters.patch
    └── playground/open_duck_mini_v2/xmls/open_duck_mini_v2_backlash.xml
```

---

## 三、改了哪些、为什么

### 1. `actuator/friction_dr_bam.py` —— 修一个 AttributeError

`FrictionDRBamActuator.initialize()` 里缺了 `q_target_smooth` 的初始化，
走 mjlab 这条路径时会抛 `AttributeError`。补上即可，不影响 BAM 的辨识语义。

### 2. `tasks/__init__.py` —— 注册两个新任务

- `Mjlab-Jump-Flat-CrazyChick` —— 跳跃任务，**62 维观测 / 15 维动作**
- `Mjlab-Velocity-Flat-OpenDuck` —— 速度跟踪任务，**61 维观测 / 14 维动作**（SolidWorks 导出形态）

> 观测/动作维度是**硬契约**：训出来的 ONNX 输入输出必须和板端 `robotd` 期望的维度一致，
> 维度不对会在上板推理时直接报错。

### 3. `microduck_roller_standup_env_cfg.py` —— 修 CUDA 越界

`_LEG_JOINTS` / `_NECK_JOINTS` 用的还是「16 个舵机」的索引，但滚轮关节被 `passive_` 过滤掉之后
实际只剩 14 个，索引会越界。改成 14 舵机视图的 0–13 后正常。

### 4. `robot/crazy_chick/` —— 整套自研仿真模型

从 SolidWorks 结构件导出、重算质心与惯量后生成的 MJCF，包含：

- `crazy_chick_walk.xml` 系列 —— 走步任务用
- `*_allcollisions*.xml` —— 打开全部碰撞体（含滚轮变体），用于排查自碰撞
- `*_backlash*.xml` —— 带**齿隙/回差**建模的变体（舵机减速箱回差是 sim2real 的主要 gap 之一）
- `open_duck_walk.xml` —— SolidWorks 形态的 Open Duck，配套 `open_duck_assets/` 网格

配套的 `assets/params_sts3215_m6.json` 是 STS3215 舵机的作动器参数。

### 5. `Open_Duck_Playground/…/open_duck_mini_v2_backlash.xml` —— 12 V 参数

上游默认按 7.4 V 的舵机特性给的增益与限幅。换 12 V 供电后阻尼、摩擦损耗、armature、
kp、力范围都要跟着改，于是新增了一个 `sts3215_12v` 执行器类，并把各关节的
`class="sts3215"` 改为 `class="chosen_actuator"`。

---

## 四、怎么把改动放回上游仓

> 前提：上游仓已经 pull 到与本目录记录时相同的基线；若上游又更新过，应用补丁可能冲突，
> 冲突时请以 `patches/*.patch` 为准人工合并。

### microduck_rl

```bash
git clone https://github.com/pollen-robotics/microduck_rl.git
cd microduck_rl
git checkout develop

# 1) 应用对官方文件的修改
git apply /path/to/OptiDuck/training/microduck_rl/patches/tracked_changes.patch

# 2) 复制新增文件（保持相对路径）
cp -r /path/to/OptiDuck/training/microduck_rl/src/mjlab_microduck/robot/crazy_chick  src/mjlab_microduck/robot/
cp    /path/to/OptiDuck/training/microduck_rl/src/mjlab_microduck/tasks/*.py       src/mjlab_microduck/tasks/
cp    /path/to/OptiDuck/training/microduck_rl/scripts/*.py                          scripts/
cp    /path/to/OptiDuck/training/microduck_rl/tests/test_roller_standup_cfg.py      tests/
```

### Open_Duck_Playground

```bash
git clone https://github.com/apirrone/Open_Duck_Playground.git
cd Open_Duck_Playground
git apply /path/to/OptiDuck/training/Open_Duck_Playground/patches/0001-12v-parameters.patch
```

---

## 五、和 `microduck_rl` 子模块的关系

主仓根目录的 `microduck_rl/` 是**子模块**（可编译、可跑训练的那份）；
本目录的 `training/microduck_rl/` 是**改动集**（小而全，方便看懂与复用）。

两者内容有重叠但不完全等同：子模块里还包含 HD1910 台架标定数据、BAM 参数、
训练权重归档等大体积内容，那些走 Release 发布，不在这里。

---

## 六、许可

见仓库根目录 [NOTICE.md](../NOTICE.md) §3。
`microduck_rl` 为 Apache-2.0；`Open_Duck_Playground` 上游未声明许可证文件，
此处仅作学习记录保留，再分发前请与原作者确认。

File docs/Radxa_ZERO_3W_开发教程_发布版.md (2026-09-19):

# Radxa ZERO 3W 机器人开发实战：模型训练、上板部署与 Rust 开发

**摘要**：本文承接《[Radxa_ZERO_3W_部署调试教程_发布版.md](./Radxa_ZERO_3W_部署调试教程_发布版.md)》，讲的是"把软件装上之后"的事 —— 自己训练一个策略模型、导出并部署到 Radxa ZERO 3W 上、调试舵机与各类传感器、改一行 Rust 代码并在一分钟内推到板子生效。全文覆盖三条链路：**模型链路**（训练 → 导出 ONNX → CPU 彩排 → 发布/占槽 → 上板）、**硬件链路**（舵机总线、IMU、ToF、摄像头的体检与排障）、**代码链路**（`dev-push` 的交叉编译、签名、健康门与回滚）。文中所有命令、寄存器值、版本号、报错原文与判定阈值均来自实机记录，可直接照做。**前置条件**：已按部署篇把板子配好（能 SSH、`robotctl` 已装、7 个守护进程在跑），并具备 Linux 命令行、SSH、PowerShell 的基本使用能力，对强化学习（PPO）与 Rust 有初步了解。文末附常见问题速查表、参考资料索引、参考来源、待核实事项与更新日志。

**图例说明**（全文只用这一套标记）：

| 标记 | 含义 |
| ---- | ---- |
| **【无需硬件】** | 不接舵机 / 传感器也能做完 |
| **【需硬件】** | 必须硬件就绪（舵机、摄像头、ToF HAT 等）才可执行 |
| **【原理】** | 解释性内容，赶时间可跳过 |
| **⚠️** | 已知的坑、或容易失败的地方 |

> **关于路径**：下文出现的 `~/microduck`（上板软件栈仓库）、`~/microduck_rl`（强化学习训练仓库）以及 `~/OpenMicroDuck`（硬件资料仓库）都是**示例路径**，请替换为你自己的本地工作目录；出现 `C:\Users\<你的用户名>` 的地方同理。出现 `<板子IP>` 的地方，替换为板子的局域网地址。本教程使用的参考板为 Radxa ZERO 3W（RK3566 / 2GB LPDDR4 / 无 eMMC），实测数据见各节标注 —— **不同批次的板子可能不同，请以自己板子的实测为准**。

## 本文目录

- [0. 开篇：路线图与三个仓库](#0-开篇路线图与三个仓库)
  - [0.1 三条链路与心智模型](#01-三条链路与心智模型)
  - [0.2 三个仓库、一个外部分发站](#02-三个仓库一个外部分发站)
- [1. 先建立全局观：这个系统是怎么长在一起的](#1-先建立全局观这个系统是怎么长在一起的)
  - [1.1 一张图认识 7 个守护进程](#11-一张图认识-7-个守护进程)
  - [1.2 两个必须分清的词：`slot` 与 `skill`、`policy` 与 `detector`](#12-两个必须分清的词slot-与-skillpolicy-与-detector)
  - [1.3 三条更新通道：什么走哪条，为什么](#13-三条更新通道什么走哪条为什么)
  - [1.4 三板斧（先记住，后面反复用）](#14-三板斧先记住后面反复用)
- [2. 模型部署：从训练到上板（全链路）](#2-模型部署从训练到上板全链路)
  - [2.1 训练一个走路策略（最短路径）](#21-训练一个走路策略最短路径)
  - [2.2 导出 ONNX（归一化会被烤进模型）](#22-导出-onnx归一化会被烤进模型)
  - [2.3 CPU 彩排：上真机前的最后一次检查](#23-cpu-彩排上真机前的最后一次检查)
  - [2.4 发布到 HF Hub：一个模型变成一个"仓库"](#24-发布到-hf-hub一个模型变成一个仓库)
  - [2.5 策略上板：五条命令全场景](#25-策略上板五条命令全场景)
  - [2.6 检测器模型：另一条链（YOLO → RKNN）](#26-检测器模型另一条链yolo--rknn)
  - [2.7 NPU 推理链路：模型在板子上到底怎么跑](#27-npu-推理链路模型在板子上到底怎么跑)
  - [2.8 两条模型链路对照表](#28-两条模型链路对照表)
- [3. 硬件调试：从体检到动起来](#3-硬件调试从体检到动起来)
  - [3.0 硬件地图：这条鸭子身上有什么](#30-硬件地图这条鸭子身上有什么)
  - [3.0.1 舵机选型：HD1910 与官方 XL330](#301-舵机选型hd1910-与官方-xl330)
  - [3.0.2 采购清单：硬件到手前先对一遍（OpenMicroDuck BOM）](#302-采购清单硬件到手前先对一遍openmicroduck-bom)
  - [3.1 硬件体检【无需硬件】：先养成这个习惯](#31-硬件体检无需硬件先养成这个习惯)
  - [3.2 舵机总线调试【需硬件】：Dynamixel 链](#32-舵机总线调试需硬件dynamixel-链)
  - [3.3 IMU【需硬件】：姿势的裁判](#33-imu需硬件姿势的裁判)
  - [3.4 ToF【需硬件】：HAT 上的 8×8 深度矩阵](#34-tof需硬件hat-上的-88-深度矩阵)
  - [3.5 摄像头【需硬件】：看世界的眼睛](#35-摄像头需硬件看世界的眼睛)
  - [3.6 音频【需硬件】：一句话带过](#36-音频需硬件一句话带过)
  - [3.7 常见硬件故障速查表](#37-常见硬件故障速查表)
- [4. 软件开发：改代码，推到板子上](#4-软件开发改代码推到板子上)
  - [4.1 代码结构：一个 workspace，七个 daemon](#41-代码结构一个-workspace七个-daemon)
  - [4.2 一次性准备（只在第一台板子做一次）](#42-一次性准备只在第一台板子做一次)
  - [4.3 dev-push 闭环：改一行 → 板子上看到它](#43-dev-push-闭环改一行--板子上看到它)
  - [4.4 第一个真实改动：加一条"被摸"日志](#44-第一个真实改动加一条被摸日志)
  - [4.5 示例项目：spaces/ 里有什么](#45-示例项目spaces-里有什么)
  - [4.6 调试三板斧（按顺序用）](#46-调试三板斧按顺序用)
  - [4.7 dev-push 常见错误速查](#47-dev-push-常见错误速查)
- [5. 端到端演练：给鸭子加一个"被摸会回应"的行为](#5-端到端演练给鸭子加一个被摸会回应的行为)
- [6. 常见问题速查](#6-常见问题速查)
- [7. 参考资料索引（按主题）](#7-参考资料索引按主题)
- [参考来源](#参考来源)
- [待核实事项](#待核实事项)
- [更新日志](#更新日志)

---

## 0. 开篇：路线图与三个仓库

这一节先给出全局图景：三条链路各自解决什么问题，以及手上有哪几个代码仓库。**建议在动手前先通读一遍**，后面每一节都能对回这张图。

### 0.1 三条链路与心智模型

三条链路在本文各占一节：

```mermaid
flowchart LR
  subgraph M["模型链路 §2"]
    M1["训练 PPO<br/>microduck_rl"] --> M2["导出 ONNX<br/>scripts/export.py"] --> M3["转 RKNN<br/>检测器<br/>to_rknn.py"] --> M4["发布到 HF Hub<br/>policies /<br/>duck-detector"]
  end
  subgraph C["代码链路 §4"]
    C1["改代码"] --> C2["交叉编译"] --> C3["dev-push.sh<br/>打包 + 签名 + apply + 健康门"]
  end
  subgraph H["硬件链路 §3"]
    H1["robotctl<br/>health / monitor"]
    H2["舵机 · IMU · ToF · 摄像头"]
  end
  M4 -->|updaterd| N1["/opt/robot/policies/current<br/>/opt/robot/detector/current"]
  C3 --> N2["/opt/robot/daemon/current<br/>release 版本"]
  N1 --> N3["robotd<br/>50 Hz 控制循环"]
  N2 --> N3
  N3 --> H2
  H1 -.->|观测| N3
```

> **图 0**：三条链路各自的起点与终点 —— 模型与代码都是"往上送"（送到板子的 `current` 符号链接），硬件则是被 `robotd` 驱动、被 `robotctl` 观测的对象。三条链路的关系在这里一眼可见，后面每节都能对回这张图。

一句话版本：

- **模型 = 被动数据**（`.onnx` / `.rknn` + `manifest.json`），走 **HF Hub → updaterd** 通道，更新**不重启 daemon 之外的任何东西**，随时可以回退；
- **代码 = 主动逻辑**（Rust 二进制 + 板级脚本），走 **dev-push / release** 通道，每次替换都要过**签名校验 + 健康门 + 自动回滚**；
- **硬件 = 被调试的对象**，全部以 `robotctl health` / `monitor` 为观测入口。

> 💡 **部署篇讲"装"，本篇讲"造"。** 部署篇里出现过的 `policies/current → seed-v5`、`detector/current → seed-duck-v1` 这两个符号链接，就是模型链路的终点 —— 读完 §2 你会知道它们是怎么被填上的、以及如何填上自己的模型。

### 0.2 三个仓库、一个外部分发站

**三块代码、三个仓库**，先建立这个概念：

| 仓库 | 示例本地路径 | 干什么 |
| ---- | ---- | ---- |
| `microduck` | `~/microduck` | **上板软件栈**：7 个 Rust daemon、`robotctl`/`duckctl`、板级脚本。开发主要在这里 |
| `microduck_rl` | `~/microduck_rl` | **强化学习训练**：MuJoCo + PPO 训走路/站立/翻跟头，导出 ONNX |
| `duck_detector`（外部） | 在 GitHub / HF 上 | **检测器训练**：YOLO 模型训练 + ONNX→RKNN 转换（不在本地仓库里） |

还有一个"仓库"不是代码：**Hugging Face Hub**。策略（`microduck-*`）、检测器（`microduck-duck-detector`）都以"文件 + 一个 `manifest.json`"的形式发布在 HF 上，板子通过 `updaterd` 从 HF 拉取。**模型和策略的更新不经过 daemon 发版** —— 这是全篇最重要的概念之一。

对新手而言，先分清这份教程的阅读路线：

| 想做什么 | 读哪节 |
| ---- | ---- |
| 先搞清楚"鸭子系统到底怎么长在一起的" | §1 |
| 训练 / 部署一个自己的策略或检测模型 | §2（全链路） |
| 调舵机、IMU、ToF、摄像头 | §3 |
| 改 Rust 代码并推到板子上跑 | §4 |
| 把上面串起来做一个完整小功能 | §5（端到端演练） |

> 训练链路用到 `uv`（一个包与命令管理器，可为每条命令单独创建隔离环境，速度快、兼容性好）；代码链路用到 Rust 工具链与 `cargo`。这些工具的具体安装方法在各节分别给出。

## 1. 先建立全局观：这个系统是怎么长在一起的

### 1.1 一张图认识 7 个守护进程

部署篇只讲"如何装上"，没有说明它们各自是什么。这里补充（来自 `docs/design/architecture.md`）：

```mermaid
flowchart LR
  subgraph CORE["JSON-RPC 2.0 · 一行的 NDJSON · unix socket"]
    R1["robotd（50 Hz 控制循环，唯一能碰电机的人）"]
    R2["configd（Wi-Fi/名字/配对）"]
    R3["tofd（ToF 8×8 深度矩阵，只发不收）"]
  end

  E1["手柄"] -->|"BLE"| P1["padd"]
  E2["手机"] -->|"BLE"| P2["btd"]
  E3["SSH（robotctl）"] -->|"ssh"| P3["robotctl"]
  E4["远端"] -->|"WebRTC"| P4["mediad"]
  E5["GitHub release"] -->|"https"| P5["updaterd"]

  P1 --> CORE
  P2 --> CORE
  P3 --> CORE
  P4 --> CORE
  P5 --> CORE

  CORE -->|"一条 Dynamixel UART（/dev/ttyS2）"| M1["15 个舵机 + IMU（id 200，本教程参考板使用的 HD1910）"]
```

> **图 1**：7 个守护进程与外部入口的关系——外部入口经 unix socket 接入板内的 `robotd` / `configd` / `tofd`，再由 `robotd` 通过一条 Dynamixel UART 驱动舵机与 IMU。

**三个必须记住的硬规则**（后面调试全靠它们）：

1. **`robotd` 是唯一能命令电机的人。** 其他进程只能发"意图"（走多快、看哪里、站起来），安全性由 `robotd` 裁决。所以舵机总线出问题，先怀疑 `robotd`。
2. **`configd` / `updaterd` / `btd` 不依赖 `robotd`。** 机器人控制循环挂掉时，仍可改 Wi-Fi、更新、回滚——这是"永不砖"的根基。
3. **服务和数据分两条路：** 命令/状态走 unix socket JSON-RPC（控制面），视频/音频帧**绝不**走 socket（数据面）。所以"摄像头画面卡了"和"电机不动了"永远是两个问题。

### 1.2 两个必须分清的词：`slot` 与 `skill`、`policy` 与 `detector`

| 词 | 意思 | 例子 |
| --- | --- | --- |
| **slot（槽位）** | 机器人**默认**跑什么：7 个固定槽位 `walk`/`stand`/`sitstand`/`ground_pick`/`kick_left`/`kick_right`/`roulade` | `walk` 槽装走路步态 |
| **skill（技能）** | 机器人**被要求时**跑什么：一次性的动作，跑完自己回去 | 鞠躬`polite-bow`、前滚翻 `roulade` |
| **policy（策略）** | 从 RL 训练出的`obs[1,61] → actions[1,14]` 的 ONNX 模型 | `walk.onnx` |
| **detector（检测器）** | 从图像训练出的目标检测模型（YOLO），输入 320×320 帧，输出 2100 个候选框 | `duck_detect.rknn`（NPU）/ `.onnx`（CPU 兜底） |

```text
robotctl policy list   # 看 7 个槽位 + 已装的 skills
robotctl policy add polite-bow <HF repo>   # 加一个技能
robotctl robot do polite-bow               # 让它跑一下
```

> 💡 **`slot` 由配置指向某个模型文件，`skill` 由名字被调用。** 一个策略文件放对地方（槽位/技能），就是"部署"的全部。

### 1.3 三条更新通道：什么走哪条，为什么

| 更新内容 | 通道 | 门槛 | 失败后果 |
| --- | --- | --- | --- |
| **策略 / 检测器模型** | HF Hub →`updaterd`（`robotctl policy update` / `robotctl duck-detector update`） | 只需`manifest.json` 字段合法 | 拒绝安装，现有模型不动 |
| **daemon 代码（发版）** | GitHub release →`robotctl update apply daemon` | 签名 + 健康门 | 自动回滚到上一个 release |
| **你的开发代码** | `dev-push.sh`（用开发密钥签名）→`robotctl update apply --from` | 开发板 + dev key | 同上，自动回滚 |

**为什么模型单独一条通道？** 因为"换一个策略"和"换一个 daemon"是两种风险等级：
策略文件是数据，`robotd` 每次加载前都会校验形状（`obs_len`/`action_len`/`model_api`/`robot.model`），
错了顶多拒绝加载；而 daemon 二进制是代码，错了可能让板子失联，所以必须过签名 + 健康门 + 回滚。
记住这个分层，后面所有操作都不迷路。

### 1.4 三板斧（先记住，后面反复用）

```bash
robotctl version          # 每个 daemon 实际跑的版本 vs 已安装版本（先跑这个，别信记忆）
robotctl health           # 硬件 + 软件一份报告；不健康时退出码非 0（可接脚本）
robotctl monitor          # 实时：指令 vs 实际、IMU 重力、循环频率、电量和温度
```

`robotctl monitor` 是调试主力，先记几个键：`q` 退出、`t` 打开 ToF 矩阵、`c` 打开摄像头、
`d` 关掉右侧机器人小图、`p` 打开手柄输入流。终端不够宽时按 `d` 关掉机器人图。

## 2. 模型部署：从训练到上板（全链路）

> 目标：本节结束后，可以把一个**自己训出来的模型**（或仓库里已有的模型）放到鸭子上跑起来，
> 并知道每一步卡住时去哪查。全链路五段：

```mermaid
flowchart LR
  A1["① 训练（microduck_rl）：uv run train"] --> A2["② 导出 ONNX：export.py"]
  A2 --> A3["③ 彩排（CPU）：infer_policy / policy-rehearsal"]
  A3 -.->|"可选分叉：要叫名字 / 绑手柄 / 分享"| A4["④ 发布到 HF Hub：uv run publish"]
  A3 -->|"只在自己板子上用（local 来源）"| A5["⑤ 上板占槽 / 发布：robotctl policy / duck-detector"]
  A4 --> A5
  A5 --> A6["板子上生效"]
```

> **图 2**：从训练到板子上生效的完整链路，其中"④ 发布到 HF Hub"是可选的虚线分叉。

**④ 的取舍**是：自己板子上用 → 跳过 ④，ONNX 拷到板子直接占槽位（local 来源）；要叫名字/绑手柄/分享 → 先 ④（`uv run publish`），再装成技能。

策略和检测器是**两条平行的链**（训练仓不同、转换不同、上板命令不同），分开讲，最后汇总一张对照表。（uv 是一个包及命令管理器，可以为每个命令单独创建环境运行，速度快、兼容性好）

### 2.1 训练一个走路策略（最短路径）

训练仓是 `microduck_rl`，基于 mjlab（MuJoCo + Warp）跑 PPO（rsl_rl）。

mjlab：一个物理机器学习模型，用来分配及观测每次**PyTorch**的结果。一次训练迭代流程如下

1. > **mjlab 重置并并行运行数千个仿真环境**
   > 基于 MuJoCo Warp，在 GPU 上批量步进物理世界。
   >
2. > **策略网络（PyTorch）接收观测，输出动作**
   > 观测是 PyTorch 张量，策略网络也是 PyTorch `nn.Module`，两者共享 GPU 内存，零拷贝。
   >
3. > **mjlab 把动作送入物理引擎，计算新观测和奖励**
   > 奖励、终止条件、课程学习、域随机化都由 mjlab 定义。
   >
4. > **RSL-RL 等算法层用 PyTorch 计算损失和梯度**
   > mjlab 收集 rollout 数据，RSL-RL 调用 PyTorch 的 `autograd` 和 `optimizer` 更新策略参数。
   >
5. > **循环直到策略收敛**
   > mjlab 负责“跑环境”，PyTorch 负责“学参数”。
   >

**第一目标是跑通冒烟测试**，不是训出好策略——冒烟测试 1–2 分钟，能拦下约 95% 的配置错误
（这是 `microduck_rl/AGENTS.md` 的原话：*Never launch a long run without one*）。

```bash
cd ~/microduck_rl

# 0) 先同步依赖（uv 管理，装好 uv 后）
uv sync

# 1) 冒烟测试（必须先跑；64 envs × 5 iterations，1–2 分钟）
uv run train Mjlab-Velocity-Flat-MicroDuck --env.scene.num-envs 64 --agent.max_iterations 5

# 2) 正式训练（需要 CUDA GPU；8–12 GB 显存用 1024 envs，≥16 GB 用 4096）
uv run train Mjlab-Velocity-Flat-MicroDuck \
  --env.scene.num-envs 1024 \
  --agent.max_iterations 15000

# 3) 续训（从某个 checkpoint 接着跑）
uv run train Mjlab-Velocity-Flat-MicroDuck \
  --env.scene.num-envs 1024 \
  --agent.load-checkpoint logs/rsl_rl/velocity/<run>/model_15000.pt \
  --agent.resume True \
  --agent.max_iterations 30000
```

来源：`docs/training_config_velocity_hd1910.md` §10 训练命令、`microduck_rl/AGENTS.md` Commands。

**训练产物**：`logs/rsl_rl/velocity/<timestamp>/model_<iter>.pt`；
曲线在 wandb 项目 `mjlab_microduck`（本地跑是离线 run：`wandb/offline-run-*`）。

#### 训练前必须懂的三件事（否则训出来的东西上不了板）

**① 观测是 61 维，全系统共享，别动它。** 布局固定：`48 维本体感受 + 13 维命令块 [twist(3), head_pose(4), body_pose(6)]`，顺序固定。新任务只改命令块的含义，**不能删槽位**
（AGENTS.md Invariants 第一条）。全零命令 = 站立——这是部署时的空闲状态，必须显式训练过。

**② 关节布局是 14 个舵机**，`ctrl idx = joint idx`：

```text
0–4   左腿：hip_yaw, hip_roll, hip_pitch, knee, ankle
5–8   脖子/头：neck_pitch, head_pitch, head_yaw, head_roll
9–13  右腿
```

**MDP** 是 **Markov Decision Process** 的缩写，中文叫  **马尔可夫决策过程** 。它是强化学习里描述“智能体如何在一系列状态下做决策”的数学框架。

写 MDP 时永远用 `_servo_joint_ids` / `_servo_joint_pos` 辅助函数取关节下标，
**不要硬编码**（换带被动关节的模型时下标会错位）。

**③ 执行器是 BAM 模型**（电压控制的作动器，摩擦力由执行器自己算）。电机参数按型号分开存：
`microduck_rl/vendor/bam/bam/params/hd1910/*.json`（本教程参考板使用的型号）/ `hls2909`（另一款）。
训练、彩排命令都要带对应 `--motor hd1910`（§2.3）。`dof_frictionloss` 在 BAM 下是零——
给关节摩擦加 DR **（Domain Randomization，域随机化）**要缩放执行器的 `friction_scale`，否则是静默的无效操作。
**为什么按型号分开？因为换执行器 = 重训策略**：官方 XL330 的 ONNX 是给 XL330 的 BAM M6
执行器模型训的，直接换到 HD1910 上不能 bit-exact 复用（OpenMicroDuck `docs/servo.md` §1），
电机型号写在训练/彩排命令里（`--motor hd1910`），从源头就锁对执行器参数。

#### 训练纪律（少走几个月的弯路）

- **奖励符号：** `microduck_mdp` 里自取负的惩罚项（`*_penalty` / `*_l1` 返回 ≤ 0）要用**正权重**，
  否则双重取负变成"奖励违规"。铁律：每个 `Episode_Reward/<penalty>` 在 wandb 里必须 ≤ 0。
- **预算参考：** 简单一次性动作 ≈ 1000 iterations（4096 envs）；走路等复杂步态 4000–6000。
- **失败先测再改：** 别凭感觉调奖励，先 headless 评估 checkpoint，很多"失败"只是 checkpoint 太早。

> 💡 **当前板子实况：** 板子上 `policies/current → seed-v5` 是官方策略集。训练的第一步
> 不是替换它，而是先在 PC 上跑通"冒烟 → 导出 → 彩排"，等 §2.3 的彩排通过再谈上板。

### 2.2 导出 ONNX（归一化会被烤进模型）

训练完的 checkpoint 不能直接用，必须走**官方导出器**——它会把观测归一化
（`obs_normalization=True`）**烘焙进 ONNX**。手工转换会丢掉归一化，在仿真里玩看不出问题
（play 时环境会再归一化一次），上了真机才露馅。这是 AGENTS.md 明确警告过的坑。

```bash
# 方式 A：从 wandb run 导出
uv run scripts/export.py Mjlab-Velocity-Flat-MicroDuck --wandb-run-path <entity/project/run_id>

# 方式 B：从本地 checkpoint 导出（最常用）
uv run scripts/export.py Mjlab-Velocity-Flat-MicroDuck \
  --onnx-file walk_hd1910.onnx --checkpoint <iter>
```

例如需要导出以下目录中的模型：`~/microduck_rl/logs/rsl_rl/velocity/2026-09-15_20-44-58_prebom_resume`

实际命令为：

```Shell
# 1) 切到训练仓库根目录（导出器按相对路径找 logs/）
cd ~/microduck_rl

# 2) 导出 model_7750.pt → walk_hd1910.onnx（归一化自动烤进 ONNX）
uv run scripts/export.py Mjlab-Velocity-Flat-MicroDuck `
  --checkpoint-file "~/microduck_rl/logs/rsl_rl/velocity/2026-09-15_20-44-58_prebom_resume/model_7750.pt" `
  --onnx-file walk_hd1910.onnx

# 3) 确认产物（应显示 walk_hd1910.onnx，约几十 MB）
Get-ChildItem walk_hd1910.onnx | Select-Object Name, Length, LastWriteTime
```

3D演示模型的命令如下：

```Shell
cd ~/microduck_rl

uv run play Mjlab-Velocity-Flat-MicroDuck `
  --checkpoint-file "~/microduck_rl/logs/rsl_rl/velocity/2026-09-15_20-44-58_prebom_resume/model_7750.pt" `
  --num-envs 1
```

导出实现（`microduck_rl/src/mjlab_microduck/export.py` L251-L269）的核心动作：
`runner.export_policy_to_onnx` 只导出 actor（critic 不上板），把观测归一化的均值/方差写成
ONNX 常量，并把 `model_api`、`obs_len`、`action_len` 等写进 metadata。

**产出契约**（也是板子校验的契约，见 `docs/recurrent-policies.md` 与 `docs/policy-manifest.md`）：

| | 输入 | 输出 |
| --- | --- | --- |
| 前馈模型 | `obs [1, 61]` | `actions [1, 14]` |
| LSTM 模型（`model_api: 2`） | `obs [1, 61]`, `h_in`, `c_in` | `actions [1, 14]`, `h_out`, `c_out` |

所有张量 float32、按名字匹配（与顺序无关）。**LSTM 导出必须标 `model_api: 2`**，
老 daemon 会拒绝安装；前馈是 API 1。

### 2.3 CPU 彩排：上真机前的最后一次检查

彩排解决两个不同的问题，用的是两个不同的工具（**以下命令是 linux 环境**）：

| 彩排 | 在哪跑 | 回答什么问题 | 工具 |
| --- | --- | --- | --- |
| ① 训练仓彩排 | 开发机 MuJoCo 仿真 | 策略动作合不合理？能不能走/站/起身？ | `infer_policy.py`  |
| ② 上板仓彩排 | **板子上**、生产 Rust 推理路径 | 板子跑不跑得动？延迟够不够 50 Hz？ | `policy-rehearsal` |

**两者都要做，顺序不能换**：先在训练仓看动作（行为对不对），再去上板仓测延迟（性能够不够）。
下面分开讲。多数人会栽在②的一个认知上，先看②。

```mermaid
flowchart TD
  S0["CPU 彩排：上真机前的最后一次检查"] --> S1["① 训练仓彩排 — 看动作对不对（开发机 MuJoCo 仿真，infer_policy.py）"]
  S1 --> D1{"动作合不合理？能不能走 / 站 / 起身？"}
  D1 -->|"否"| F1["回到训练 / 导出（§2.1、§2.2）"]
  D1 -->|"是"| S2["② 上板仓彩排 — 测延迟（板子上跑 policy-rehearsal）"]
  S2 --> D2{"p95 / p99 / max 稳在 20 ms 内，over_20_ms 为 0？"}
  D2 -->|"否"| F2["不能上板：延迟超标，先排查"]
  D2 -->|"是"| F3["通过彩排，进入 §2.4 发布"]
```

> **图 3**：两条彩排子路径及其判定——先看动作（行为对不对），再测延迟（性能够不够），顺序不能换。

#### 2.3.1 训练仓彩排：看动作对不对（仿真）

在训练仓 `microduck_rl` 里，用 MuJoCo + 真实执行器参数（默认已是 hd1910 电机模型）把策略跑一遍：

```bash
# 训练仓（microduck_rl）目录下
uv run scripts/infer_policy.py --walking walk_hd1910.onnx --motor hd1910
```

它会弹出一个 3D 查看器，可用方向键驱动它，直观确认策略行为正常。
这一步**只验证动作合理性，测不了延迟**——仿真机比板子快，仿真时间不代表板上时间。

> 💡 前一步 §2.2 的"3D 演示"也是类似的目的（`uv run play ...`），但它加载的是 checkpoint，
> 而这里加载的是**导出后的 ONNX**——观测归一化已经烘焙进去，行为应当一致。以 ONNX 的结果为准。

#### 2.3.2 上板仓彩排：测延迟（板子跑不跑得动）

**⚠️ 摆正认知：这条彩排必须在板子上跑，不是在开发机上。**
官方文档（`docs/recurrent-policies.md` §Offline rehearsal）写得很明确：
"Run the built example **on the Radxa** to establish onboard timing;
development-host timings do not establish the robot's timing budget."
开发机的 CPU 比板子快得多，拿开发机的 p50 去判断"能不能跑 50Hz"，
等于拿 i9 的帧率给手机做性能预算。**板子的耗时才是真预算。**

彩排目标：确认策略在 **50 Hz 控制环**（每步预算 20 ms）下，推理延迟不超标。
注意这个时间**只算 actor 推理**，不含传感器读取、电机写入和调度开销。

完整步骤如下：

**第 1 步：确认模型是官方导出器导出的**（§2.2 已做）

`uv run scripts/export.py` 把观测归一化**烘焙进 ONNX**，并写入 `model_api`/`obs_len`/
`action_len` 等 metadata。手工转换丢归一化，仿真里看不出问题，上了真机才露馅。
上板前先看一眼维数契约（在开发机的 Python REPL 或 venv 里跑）：

```python
import onnx
m = onnx.load("standup_hd1910.onnx")
print([(i.name, [d.dim_value for d in i.type.tensor_type.shape.dim]) for i in m.graph.input])
# 期望: [('obs', [1, 61])]
print([(o.name, [d.dim_value for d in o.type.tensor_type.shape.dim]) for o in m.graph.output])
# 期望: [('actions', [1, 14])]
```

前馈模型是 `obs[1,61] → actions[1,14]`；LSTM 还要多出 `h_in/c_in → h_out/c_out`，
且 metadata 必须标 `model_api: 2`，否则老 daemon 会拒绝安装（§2.2 产出契约）。

**第 2 步：把模型拷到板子**

这一步用 `scp` 传文件是**正常的**——它只是把待测模型送进板子，**不等于上板部署**。
真正上板要等彩排通过之后，走 §2.4/§2.5 的发布 + `robotctl policy` 通道。

```bash
# 在开发机（Windows PowerShell）上执行
scp ~/microduck_rl/standup_hd1910.onnx radxa@192.168.31.30:/home/radxa/

# 传完先核对 MD5，防止传输损坏（坏模型会给出完全不同的彩排结果）
# 开发机: Get-FileHash standup_hd1910.onnx -Algorithm MD5
# 板子上: md5sum /home/radxa/standup_hd1910.onnx
```

**第 3 步：确认板子彩排前置条件（Rust + ONNX Runtime）**

彩排要在板子上**现场编译** `duck-control`，需要两样东西，缺哪个装哪个：

```bash
# ① Rust 工具链在不在
cargo --version

# ② ONNX Runtime 动态库在不在（duck-control 通过 dlopen 加载它，不打包）
#    §7 的 setup-board.sh 装的是 1.28.0
find / -name "libonnxruntime*" 2>/dev/null
```

- **缺 Rust**（`command not found`）→ 往下看"装 Rust"小节
- **缺 ORT**（find 无输出）→ 跑 `setup-board.sh`（或单独装 ORT 1.28.0）

**→ 装 Rust（板子上没有 cargo 时执行）**

用 rustup 装到用户目录，**不需要 sudo**：

```bash
# ① 国内网络先配镜像，再装（官方源在国外，直连大概率超时；换源能省非常多时间）
export RUSTUP_DIST_SERVER=https://rsproxy.cn
export RUSTUP_UPDATE_ROOT=https://rsproxy.cn/rustup

# ② 安装（--profile minimal 只装 rustc/cargo，够编译用）
curl --proto '=https' --tlsv1.2 -sSf https://sh.rustup.rs | sh -s -- -y --profile minimal

# ③ 让当前终端生效（rustup 装完不会自动加载环境变量）
source "$HOME/.cargo/env"

# ④ 验证
cargo --version
rustc --version
```

> 💡 **镜像没配就装**：rustup 默认从 `static.rust-lang.org` 拉工具链，在板子上（尤其国内网络）经常卡死或超时。
> 上面的 `rsproxy.cn` 是字节跳动的 Rust 镜像，配完基本秒下。如果装完 cargo 还是慢（拉 crates 依赖时），
> 再配 crates 镜像：`~/.cargo/config.toml` 里写 `[source.crates-io] replace-with = 'rsproxy'` + 对应 registry 地址（教程 §10 有完整配置示例）。

彩排**不碰电机总线**，所以不需要电机上电、不需要接舵机——板子空转也能测。

**第 4 步：把上板仓代码弄到板子**

彩排的 `cargo run` 必须在上板仓目录内执行（那里才有 `Cargo.toml`），而板子上默认**没有**上板仓代码——
新手最容易在这里卡住：在 `~` 下跑 `cargo run` 报 `error: could not find Cargo.toml in /home/radxa`。
所以先把上板仓源码弄到板子上：

```bash
# ① 在板子上，下载并解压上板仓（用 codeload 下载 tar.gz）
#    GitHub 直连（github.com）在板子上经常超时，codeload 是官方内容分发域名，稳得多
cd /home/radxa
curl -L -o microduck.tar.gz https://codeload.github.com/pollen-robotics/microduck/tar.gz/refs/heads/main
tar -xzf microduck.tar.gz
ls   # 应看到 microduck-main 目录

# ② 先配 crates 镜像再编译（板子上拉 crates 依赖，不配镜像会非常慢甚至失败）
mkdir -p ~/.cargo
cat > ~/.cargo/config.toml <<'EOF'
[source.crates-io]
replace-with = "rsproxy"

[source.rsproxy]
registry = "sparse+https://rsproxy.cn/index/"

[registries.rsproxy]
index = "sparse+https://rsproxy.cn/index/"

[net]
git-fetch-with-cli = true
EOF
```

> ⚠️ **复制粘贴反引号陷阱（真实踩坑）**：本文档的 URL 在界面里渲染成代码样式（两边带反引号 `` ` ``）。
> 从对话/文档**复制 heredoc 时，这些反引号会被一起复制进文件**，导致 cargo 解析 URL 失败。
> 症状：`cat ~/.cargo/config.toml` 看到 `registry = "sparse+`https://...`"` 两边带反引号。
> 修复：`sed -i 's/`//g' ~/.cargo/config.toml`（或干脆用下面的 scp 方案重写）。
> **最稳妥的做法**：不在板子上粘贴含 URL 的命令，而是从开发机生成配置文件再 scp 上去：

```powershell
# 在开发机（Windows PowerShell）生成干净配置，scp 到板子覆盖
# （本地建一个 cargo-config.toml，内容就是上面 heredoc 里的 6 行，确保 URL 无反引号）
scp cargo-config.toml radxa@192.168.31.30:/home/radxa/.cargo/config.toml
# 上板后验证：cat ~/.cargo/config.toml 应看到 registry = "sparse+https://rsproxy.cn/index/" 无反引号
```

> `sparse+` 是 rsproxy 官方推荐的增量 index 格式，比整包 git 拉 index 快很多，板子必用。

> 💡 **为什么用官方 `pollen-robotics/microduck`**：板子的更新器（`updater.toml`）配的就是这个仓库、
> 板上 daemon 也是它的代码。彩排的意义就是测**和板上相同代码**的推理路径，所以必须用同一个仓库。
> 注意：本地 `~/microduck` 这个目录**也只是官方仓库的一份 clone**（remote 指向
> `pollen-robotics/microduck`，本地无私有提交）——GitHub 上并不存在独立的第三方版上板仓。
> 国产化（HD1910 电机参数等）都在训练仓 `microduck_rl`、已烤进 ONNX，上板仓保持纯官方即可。

**第 5 步：在板子上编译并运行彩排**

```bash
# 在板子上、上板仓目录内执行（第 4 步解压出的 microduck-main）
cd /home/radxa/microduck-main
export ORT_DYLIB_PATH=/usr/local/lib/libonnxruntime.so   # 第 3 步 find 到的实际路径
cargo run --release -p duck-control --example policy-rehearsal -- \
  /home/radxa/standup_hd1910.onnx > rehearsal.json

# 查看结果
cat rehearsal.json
```

首次编译要拉依赖 + 编译 release，会花几分钟；之后的 `cargo run` 增量编译就快很多。
**板子上网不便时**：可以在开发机用 `cargo build --release` 交叉编译出二进制拷过去，
但 ORT 动态库必须是板子上的（架构一致），且**时间必须在板子上实测**——交叉编译只是省编译时间，不能省实测。

**第 6 步：解读结果，判断能否上板**

```json
{
  "steps": 1000,
  "latency_ms": {"p50": 2.1, "p95": 3.4, "p99": 5.2, "max": 9.8},
  "over_20_ms": 0,
  "actions": [[...], [...], ...]
}
```

判定标准：

| 指标 | 要求 | 说明 |
| --- | --- | --- |
| `p95`/`p99` | 明显低于 20 ms | 50 Hz 控制环每步预算 20 ms，尾部延迟太高会周期超时 |
| `over_20_ms`  | 最好是 0 | 超过 20 ms 的次数；非 0 意味着有控制步会被拖过预算 |
| `max` | 越低越好（首推可能偏高属正常，预热已做） | 峰值延迟，决定最坏情况 |
| `actions` | 与前馈推理逐项对比（可选） | 用带 obs 的 trace 对比 PyTorch/Python ORT，校验推理一致性 |

只有板子上测出的 `p95/p99/max` 都稳在 20 ms 内、`over_20_ms` 为 0，策略才算通过彩排，
可以进入 §2.4 发布。**不要**用开发机的测量结果替代——那只能证明模型结构没问题，
证明不了板子跑得动。

> ⚠️ **彩排 ≠ 上板**：彩排只是"用生产推理路径测延迟"，它**不写任何板子配置、
> 不占策略槽位、不需要电机**。真正把策略装进板子（`robotctl policy add`/`load`）是
> 彩排通过之后、发布完成之后的事（§2.5）。别把这两步搞混——彩排阶段就把模型
> `robotctl policy load` 进槽位，属于跳过流程的误操作。

### 2.4 发布到 HF Hub：一个模型变成一个"仓库"

> 💡 **先分流：发布不是必经之路**。如果模型只在本地板子上使用，可以跳过本节，
> 直接走 §2.5 的 `sudo robotctl policy load <槽位> /home/radxa/xxx.onnx`（本地文件占槽，
> 持久生效）。走发布的意义：叫名字触发（`robot do`）、绑手柄按钮、分享给他人、
> 有 manifest 校验和版本管理。两条路见 §2.5 末尾的对比。

**发布前置：HF 登录（一次性的）。** `uv run publish` 走 `huggingface_hub` 上传，
token 从两个地方找，**没有 token 就无法发布**（报 `no cached HF token. Run hf auth login.`）：

> ⚠️ **注意**：本节的登录、发布命令都在开发机上执行（发布模型的是开发机）。板子**不需要**
> HF token——它只通过 `robotctl policy add` 拉取**公开**策略仓，匿名即可；
> 在板子上跑 `hf auth login` 会报 `hf: command not found`（板子没装这套工具，也不需要）。

**先创建 token（第一次用 HF 时，网页操作，只需一次）：**

1. 打开 [https://huggingface.co/settings/tokens](https://huggingface.co/settings/tokens)（需已注册/登录 HF 账号），
   点 **Create new Access Token**
2. **Token type**：保持默认的 **Fine-grained**（不用动；创建后不可改）
3. **Token name**：随便起个名字（如 `microduck-publish`），方便以后辨认
4. **Presets**（预设按钮）：点 **⬆ Write** —— 这正是发布需要的权限集（对账号名下仓库的
   读+写，覆盖 `create_repo` + `upload_folder`）。**不要选 Read-Only**（上传 401/403），
   也不必选 Full Access（权限过大没必要）；Custom 手动勾细项是给特殊场景的，发布用不上
5. 点 **Create token**，弹出 `hf_xxxxx` 后**立刻复制**——**只显示这一次**，关掉就再也
   看不到了，丢了只能重新创建

**方式 A（推荐）：huggingface_hub CLI 登录，token 缓存到本机**

`hf` 不是系统全局命令，它装在训练仓的 venv 里——**必须通过 `uv run` 调用**（在训练仓
`microduck_rl` 目录下执行；直接敲 `hf auth login` 会报 command not found）：

```powershell
# 开发机（Windows PowerShell），先 cd 到训练仓目录
cd ~/microduck_rl
uv run hf auth login
# 按提示：粘贴 hf_xxx token → 回车；"Add token as git credential?" 选 n 也行
```

**方式 B：临时用环境变量（不写盘，仅当前终端生效）**

```powershell
$env:HF_TOKEN = "hf_xxx"     # PowerShell；Linux 用 export HF_TOKEN=hf_xxx
```

**怎么确认 token 已经就位（发布前先验证，避免白跑）：**

```powershell
# 同样在 microduck_rl 目录下
uv run python -c "from huggingface_hub import whoami; print(whoami()['name'])"
# 打印出 HF 用户名 = 登录成功；报错 = token 没配上
```

**token 权限要求**：`publish` 要在账号名下发仓库（`create_repo`）并上传文件
（`upload_folder`），必须用 **Write 权限**的 token（创建页 Presets 点 **⬆ Write** 即可；
只读 token 上传会 401/403）。`--repo <user>/microduck-<name>` 里的 `<user>` 就是
登录账号的 HF 用户名，publish 会**自动从 token 推断**——所以先登录、`<user>` 用自己账号的用户名。

> 💡 如果之后用 `uv run train ... --hf-jobs` 在 HF 上跑训练，那是另一个
> **带 Jobs 权限**的 fine-grained token，与本地发布不是一回事（`hf_jobs.py` 里
> token 鉴权通过但缺 Jobs 权限会明确报 "token-scope problem, not billing"）。

**manifest.json 是什么、为什么需要它**：板子**不认裸的 `.onnx`**。安装策略时，
`robotctl policy add` 会检查模型旁边一个 `manifest.json`——模型的"身份证"，写明：
给谁用的（`robot.model: microduck`，写错直接拒装）、输入输出维度（`obs_len: 61` /
`action_len: 14`，和板子对不上就拒装）、什么类型（episodic/perpetual）、跑几秒、
训练来源（便于溯源）。所以"发布" = **policy.onnx + manifest.json + README 三个文件
一起**上 HF Hub，板子拉取后验 manifest 通过才装。

**manifest 不需要手写**——训练仓的 `publish` 命令根据参数**自动生成**它，并做
上传前体检（61→14 维度校验 + NaN 冒烟测试），不合格不会传（`microduck_rl/AGENTS.md`）。
权重来源有两种（**下述两种来源仅作解释，已在 §2.2 导出 ONNX 时执行过**）：

```bash
# 来源 A：从 wandb 训练 run 现场导出（归一化烤进模型，最安全的路径）
uv run publish --task <TASK_ID> --wandb-run-path <entity/project/run_id> \
  --checkpoint N --repo <user>/microduck-<name> \
  --kind episodic --duration-s 4.0

# 来源 B：用已经导出好的 ONNX（§2.2 导出的就是这种）
uv run publish --onnx <文件>.onnx --repo <user>/microduck-<name> --kind episodic --duration-s 6.0
```

**`kind` 决定它装到哪（官方契约，不必自行推断）**——映射写在
`microduck_rl/src/mjlab_microduck/publish/manifest.py` 的 `install_commands()` 里，
publish 结束时会直接把第一行安装命令打印出来：

| 发布时给的 `kind` | 板子上装成 | 官方生成的安装命令 |
| --- | --- | --- |
| `episodic` | **技能**（跑完 `duration_s` 自己结束） | `sudo robotctl policy add <name> <repo>` → `robotctl robot do <name>` |
| `perpetual --unwind-s N` | **"按住"型技能**（跑完由 daemon 送 `idle` 回来） | `sudo robotctl policy add <name> <repo> --hold <秒>` → `robot do <name>` |
| `perpetual`（不给 `unwind-s`） | **槽位步态**（一直跑，直到你叫停） | `sudo robotctl policy load <槽位> <repo>` |

两个容易搞错的点：

- **`--slot` 只是"显示用"**（`Display-only; drives the install hint`）：它只决定上面打印哪条
  安装提示，**不会**自动锁死槽位。真锁槽位的是板子上那条 `policy load`。
- **同名仓库已有 `policy.onnx` 时**要加 `--force` 才能覆盖——一个仓库只放一个 `.onnx`，
  想换个名字就是新建一个仓库（`cli.py` 原话：`a second name is a new repo`）。

**实操示例：把 standup_hd1910.onnx 发布成"叫名字就起身"的技能**（开发机、训练仓目录下；
写成单行避免多行续行符的复制问题）：

```powershell
cd ~/microduck_rl
uv run publish --onnx standup_hd1910.onnx --repo <你的HF用户名>/microduck-standup --kind episodic --duration-s 6.0 --entry-pose sitting --no-private
```

| 参数 | 作用 |
| --- | --- |
| `--onnx` | 已导出的模型；publish 会先校验 61→14 维度 + 冒烟测试再传 |
| `--repo <用户名>/microduck-standup` | 发到 HF 账号下；**技能名 = `microduck-` 后面的部分**（`standup`） |
| `--kind episodic` | 一次性技能：跑完`duration_s` 自己结束——"叫一下执行一次" |
| `--duration-s 6.0` | 与训练 episode 长度一致（standup env 的`EPISODE_LENGTH_S = 6.0`），够完成起身 |
| `--entry-pose sitting` | 告诉板子这个策略从坐姿起步（默认 standing，起身模型必须改） |
| `--no-private` | **关键**：默认建私仓，而板子是匿名拉取**公开**仓——私仓板子拉不到  |

> 💡 不放心可先加 `--dry-run`：不联网，把三个文件写到本地 `publish-<name>/` 目录，
> 先看看自动生成的 manifest.json 长什么样再真发。

**另一种装法：不发技能，改走槽位（同一份 ONNX，换个 `kind`）**。若希望起身模型像
"基础功能"一样常驻（塞进 `stand` 槽，起身后一直维持站立），而不是"叫一次跑一次"：

```powershell
uv run publish --onnx standup_hd1910.onnx --repo <你的HF用户名>/microduck-standup-stand --kind perpetual --slot stand --entry-pose sitting --no-private
```

装法相应变成 `sudo robotctl policy load stand <你的HF用户名>/microduck-standup-stand`
（对照上面那张表第三行）。两条路选哪条：

| | episodic 技能（上面第一个示例） | perpetual 占槽位 |
| --- | --- | --- |
| 触发 | `robotctl robot do standup` 叫一次 | 默认就跑，一直维持 |
| 绑手柄 | 可以（`pad bind`） | 不行（槽位是默认态） |
| 结束行为 | 6 秒后 daemon 交回槽位策略 | 一直跑，策略自己闭环 |
| 适合 | "叫名字起身"、演示 | 让鸭子默认就站着 |

发布成功后，板子侧安装（§2.5 详述）：

```bash
sudo robotctl policy add standup <你的HF用户名>/microduck-standup
# 之后 robotctl robot do standup 即触发起身
```

`publish` 只允许发布**常命令的 episodic/perpetual** 策略；phase/posture 那种由 daemon 驱动的
策略（地面捡物、官方坐↔站槽位）属于官方策略集，不走这条普通发布路。注意自训起身模型
以 **episodic 技能**发布（`robot do standup` 触发）与官方的 posture 槽位机制是两条路，
互不影响。两点差异提前知道：① 官方坐↔站是 `scripted`（可中断 episodic，daemon 能在起身
中途打断），发布版 episodic **不可中断**——对起身无碍；② episodic 的结束语义是"策略自己
回到安全姿势"，起身策略 6 秒后稳定站立（站立 = 安全姿势），之后 daemon 恢复槽位控制，
由 stand 槽位策略接管维持站立。

**`manifest.json` 长什么样**（完整字段见 `docs/policy-manifest.md`，一个典型单策略仓库）：

```json
{
  "schema_version": 2,
  "model_api": 1,
  "obs_len": 61,
  "action_len": 14,
  "robot": { "model": "microduck", "hw_rev": 1, "servos": "hd1910", "control_hz": 50 },
  "name": "polite-bow",
  "kind": "episodic",
  "duration_s": 4.0,
  "chain": false,
  "entry_pose": "standing",
  "description": "Bows from a two-foot stand and comes back up.",
  "command": { "encoding": "constant", "idle": [0, 0, 0],
               "twist": "unused (zeros)", "head": "unused (zeros)", "body": "unused (zeros)" },
  "training": { "task_id": "Mjlab-PoliteBow-Flat-MicroDuck", "repo": "pollen-robotics/microduck_rl",
                "commit": "0bf9897", "branch": "bow", "dirty": false,
                "run": "pollen-robotics/mjlab_microduck/abc123", "checkpoint": 3000,
                "exported": "2026-09-02T14:05:00Z" }
}
```

> 💡 `robot.model`（`microduck`）才是**校验字段**，写错直接拒绝安装；`robot.servos`
> 只是**展示字段**（官方例子写 `xl330`，本项目参考板写 `hd1910`），不校验但写对才能溯源。
> 官方 `policy-manifest.md` 里的例子、以及 `robotctl policy add` 的校验规则都基于 `robot.model`。

**两个最关键的概念字段**（`kind` 和 `command.encoding`，板子靠它们决定怎么用这个模型）：

| `kind` | 谁结束这个策略 | 变成什么 |
| --- | --- | --- |
| `episodic`  | 自己跑`duration_s` 秒后回安全姿势 | 一次性技能（`robot do` 触发） |
| `perpetual` | 一直跑直到被告知停下 | 槽位步态（`policy load walk …`） |
| `scripted`  | 可被中断的一次性 | 记录用，daemon 自己驱动 |

| `command.encoding` | daemon 喂给它的命令 | 谁能用它 |
| --- | --- | --- |
| 缺省 /`constant` | 固定 twist，回程`idle` | 所有一次性技能 |
| `phase` | `[cos 2πφ, sin 2πφ, 0]` 随时间转 | 地面捡物（daemon 驱动，**拒绝** `policy add`） |
| `posture_flag` | 一个槽位携带 sit/stand | 坐↔站（同上，**拒绝** `policy add`） |

> 💡 一个**常命令的 `episodic`** 策略，加上 `duration_s`，就是"按名字就能调用的技能"——
> 这是社区发布策略最常用的形态。phase/posture 策略不能做成技能，装进槽位由 daemon 驱动。

### 2.5 策略上板：五条命令全场景

板子上所有策略操作都走 `robotctl policy …`（只读命令不需要 `sudo`，**改状态的要 `sudo`**）：

```bash
robotctl policy list            # 看 7 个槽位 + 已装技能（两栏表格）
robotctl policy check           # 官方策略集：已装 vs 最新 vs 仓库还提供什么（只读）
sudo robotctl policy update     # 更新到最新（--version v1 可回退到指定版本）
```

实测输出长这样（`origin` 列就是 §2.5 末尾那张来源表里的 official/community/local）：

```text
$ robotctl policy list
mode: walk

   SLOT         ORIGIN     POLICY
   walk         official   velstand.onnx
   stand        -          (none)
   sitstand     official   alpha_sitstand.onnx
   ground_pick  official   alpha_ground_pick.onnx
   kick_left    official   ball_kick_left.onnx
   kick_right   official   ball_kick_right.onnx
   roulade      official   roulade.onnx

   SKILL        RUNS FOR  POLICY
   roulade           1 s  roulade.onnx
   sit_toggle          —  driven by the robot itself
```

> 💡 **`stand` 槽默认就是空的**（`origin = -`、`policy = (none)`）：走路模式下"站着"由
> `walk` 槽的 `velstand.onnx` 兜底。所以往 `stand` 槽装自己的策略是**覆盖一个空槽**，
> 语义干净；也正因如此，`policy load stand <源>` 失败后这一行会**保持 `(none)`**，
> 是判断"有没有真的生效"最直接的一眼。

**用自己的文件占槽位（"基础功能"路线，不发布、不用 HF）**：

```bash
sudo robotctl policy load walk /home/radxa/my_walking.onnx
```

> ⚠️ **注意**：**`<源>` 的判定规则（踩过坑）**：`robotctl` 先看**这个路径在板子上存在吗**——
> 存在就当本地文件（local 来源）；**不存在就当成 `org/name` 仓库**去 HF 拉，
> 于是报 `error: network error: /path/xxx.onnx is not an org/name repo`
> （`robotctl/src/main.rs`：*"A path if it exists here; otherwise `org/name`"*）。
> 所以上面这条命令**必须先真的把文件 scp 到 `/home/radxa/`**，否则一定报错。
> 例如板上已有 `standup_hd1910.onnx`，正确的写法就是：
> `sudo robotctl policy load stand /home/radxa/standup_hd1910.onnx`

走路时会先回 home 姿势、加载、再驱动；坐着时则什么都不动——**换的不是正在跑的那个网络**。
`sudo robotctl policy reset walk` 放回原样。

> ⚠️ **注意**：这条不是"临时试试"——`policy load` 会**写入 `/etc/robot/robotd.toml` 持久生效**，
> 重启后仍指向该文件（实测确认）。所以文件**必须一直留在板子上**——文件丢了，槽位会在
> 启动时回落到官方策略并在 `robotctl health` 里报出来。

**报错 `the robot accepted the change but had not made it after 20s` 怎么读**（参考板实测）

**这不是失败**，是"**命令层成功、应用层尚未完成**"：`robotctl` 把请求交给 `robotd`，
`robotd` 收下了，但 20 秒内没做完切换，于是先这么返回，并提示自行去看结果。要分两半看：

| 半 | 状态 | 怎么验证 |
| --- | --- | --- |
| **配置写入** | ✅ 已成功 | `awk '/^\[policy\]/{f=1;next} /^\[/{f=0} f' /etc/robot/robotd.toml` —— 能看到 `stand = "/home/radxa/xxx.onnx"` |
| **live 切换** |  未生效 | `robotctl policy list` —— 该槽仍显示 `(none)`、origin `-` |

最常见的原因是 **`robotd` 卡在电机自检**（舵机没上电 / 总线没接），日志会一直刷：

```bash
echo radxa | sudo -S journalctl -u robotd -n 30 --no-pager | tail -20
# ERROR robotd: motor register check failed; waiting, is servo power on?
# error=bus transaction failed: read return_delay_time on 20: Operation timed out
# （attempt=N 每 ~45 秒 +30，N 很大说明已经卡了很久，基本就是没接舵机）
```

`Operation timed out` 后面的 `on 20` 是**正在探测的舵机 ID**（20 = 左腿髋关节）。
设备节点在不在跟舵机答不答应是两回事，先确认节点存在：

```bash
ls -la /dev/ttyS2      # 期望 crw-rw---- root dialout（存在 ≠ 舵机在线）
```

> ⚠️ **注意**：不要忽略"配置已写入"这一半——`robotd` 是**先写 `robotd.toml`、再排队切换**的
> （`docs/design/policy-channel-design.md` §3 原话：*"robotd writes the key, not the
> caller"*，理由就是让这个覆盖跨重启存活）。所以即使这里报 20 秒超时，**这份覆盖重启后
> 依然在**——硬件恢复正常后开机，该槽就会加载对应的模型。想撤销：
> `sudo robotctl policy reset <槽位>`（只撤这一个）或 `sudo robotctl policy reset`（七个全回官方）。

**槽位有三种来源，"官方槽位"不等于"只能装官方的"**（`docs/design/policy-channel-design.md` §2）：

| 来源 | 从哪来 | 自动更新 | `policy reset` 回到它 |
| --- | --- | --- | --- |
| **official** | `policies` 组件（`pollen-robotics/*`） | ✅ | ✅ |
| **community** | 任何别的 HF 仓库 | ❌ |  |
| **local** | **板子上的本地路径** | ❌ | ❌ |

来源由 HF org 判定（`pollen-robotics/*` 才算官方），不是槽位锁死的。所以自训模型
**可以占槽位**（走 local 来源），不是只能当技能。但有两条约束要知道：

- **`walk` / `stand` 是 perpetual gait 槽**（一直跑）→ 自训步态/站姿模型直接适配。
  自训起身模型走"基础功能"路线就装 `stand` 槽：
  `sudo robotctl policy load stand /home/radxa/standup_hd1910.onnx`
  （参考板实测：配置能写入 `robotd.toml`；当时仅因电机总线超时未完成 live 切换）
- **`sitstand` / `ground_pick` 是 daemon 驱动的特殊槽**：daemon 会给它喂
  `posture_flag`（sit/stand 标志）或 `phase`（相位）编码，**按 encoding 校验而不是按名字**
  （`docs/policy-manifest.md` §The two axes）。普通训练的 constant 编码模型装这两个槽
  有可能被拒或行为异常——起身模型建议走上面 `stand` 槽，或走下面的技能路线。

**装第三方的（社区）策略**：

```bash
robotctl policy search microduck
sudo robotctl policy load walk RemiFabre/microduck-flamingo-cycle
```

**加一个技能并触发（"技能"路线，衔接 §2.4 发布的 standup）**：

```bash
# 官方示例：装 polite-bow 技能并触发
sudo robotctl policy add polite-bow fffiloni/microduck-polite-bow-b1d864
robotctl robot do polite-bow

# §2.4 发布的起身模型，对应的完整链路：
sudo robotctl policy add standup <你的HF用户名>/microduck-standup
robotctl robot do standup        # "叫名字就起身"——名字 = 仓库名去掉 microduck- 前缀
```

`robot do` 需要机器人正在驱动（手柄 Start 后）。技能长度来自 manifest 的 `duration_s`。
两种路线怎么选：**自己板子日常用 → 占槽位**（`policy load`，本地文件、简单直接）；
**要叫名字触发/绑手柄/分享给他人 → 走发布 + 技能**。区别只在触发机制，模型本身没有
"技能/基础功能"属性——同一份 onnx 两条路都通（前提是装的槽位与它的 kind/encoding 匹配，
见上文 `walk`/`stand` vs `sitstand` 的说明）。

**把技能绑到手柄按钮**：

```bash
robotctl pad bindings            # 看当前绑定
sudo robotctl pad bind x polite-bow
```

写入 `[pad] x = "polite-bow"` 一行，`padd` 一秒内生效，不重启。

**校验规则（被拒绝的常见原因）**：`policy add` 在下载前就检查 `obs_len`（必须 61）、
`action_len`（14）、`model_api`（≤ daemon 的）、`robot.model`（`microduck`），
以及非 `constant` 编码——任何一项不符直接拒绝，**不会动现有策略**。

> 💡 代码侧实现：`policy.fetch` 由 `updaterd` 处理，`robot.setSkill` / `robot.policies` /
> `robot.do` 是 `duck-ipc-proto` 的现成方法名——`spaces/policy-shop/app.py` 里的"一键安装"
> 就是按这个顺序调这四个调用（详见 §4.5）。

### 2.6 检测器模型：另一条链（YOLO → RKNN）

策略是"自己训 + 导出 + 发布"，检测器链路的**转换步骤不同**——它要变成 NPU 能跑的 `.rknn`：

```text
① 训练 (duck_detector 仓)  →  ② 转 RKNN (scripts/to_rknn.py)  →  ③ 发布 HF Hub  →  ④ 上板
    yolo11n 320×320          INT8 量化 → duck_detector.rknn        同名仓发两个文件      robotctl
                             同时留 duck_detector.onnx (CPU 兜底)                        duck-detector
```

**为什么两个文件？** 板子优先跑 NPU 的 `.rknn`；NPU 不可用时回退 CPU 的 `.onnx`
（`deploy/robotd.toml` L348-358 写了这个选择逻辑）。

**上板命令**（跟策略同构，根不同、文件清单固定）：

```bash
robotctl duck-detector check           # 已装 vs 仓库最新（只读）
sudo robotctl duck-detector update     # 更新（重启 mediad，画面会断一下）
# 检测器跑不跑还受配置控制：sudo robotctl configure 里 [duck_detector] enabled
```

**首次上板机制**：`scripts/seed-detector.sh` 由 release 的 postinstall 钩子跑，
在**空板子**上按 pin 安装（`DETECTOR_REPO` / `DETECTOR_VERSION` / `DETECTOR_FILES`，脚本 L32-47），
装到 `/opt/robot/detector/releases/seed-duck-v1/` 后原子切换 `current` 符号链接
（先写 `current.new` 再 rename，脚本 L66-126）。**它绝不碰不是自己装的东西。**

**板子目录结构**（`/opt/robot` 下三条 `current` 链，是模型链路的"安装现场"）：

```text
/opt/robot/detector/current      → releases/seed-duck-v1/   # 检测器（参考板当前安装的是这个）
/opt/robot/policies/current      → releases/seed-v5/        # 官方策略集（含 manifest.json）
/opt/robot/daemon/current        → releases/<version>/      # daemon 二进制（§4 的主角）
```

### 2.7 NPU 推理链路：模型在板子上到底怎么跑

检测器的运行时绑定在 `duck-detect` crate（`docs/project/npu-bringup.md`）：

```mermaid
flowchart TD
    A1["上游模型：yolo11n 320×320（duck_detector 仓训练）"]
    A2["scripts/to_rknn.py：INT8 量化"]
    A3["duck_detector.rknn（NPU 主路径）"]
    A4["duck_detector.onnx（CPU 兜底）"]
    A5["发布：HF Hub 同名仓库两个文件"]
    A6["上板：/opt/robot/detector/current"]
    A7["板端选择：优先 .rknn，NPU 不可用时回退 CPU 的 .onnx（deploy/robotd.toml L348-358）"]
    A8["duck-detect crate（duck-detect/src/rknn.rs）"]
    A9["librknnrt.so v2.3.2（dlopen 动态加载）"]
    A10["rknn_init → rknn_outputs_get（运行时反量化成 float）"]
    A11["解码层"]
    A12["mediad（摄像头侧）"]
    A1 --> A2
    A2 --> A3
    A2 --> A4
    A3 --> A5
    A4 --> A5
    A5 --> A6
    A6 --> A7
    A7 --> A8
    A8 --> A9
    A9 --> A10
    A10 --> A11
    A11 --> A12
```

> **图 4**：检测器从训练产物到板端调用的完整链路——ONNX 经 `to_rknn.py` INT8 量化成 RKNN，由 `librknnrt.so` 在 NPU 上执行，最终由 `mediad`（经 `duck-detect` crate）调用。

- **`librknnrt.so` 是 `dlopen` 动态加载的，不是链接的**（`duck-detect/src/rknn.rs`）。
  因为它是 vendor blob、不在任何 Debian 套件里，链接它就没法在 CI 交叉编译；
- **运行时反量化**：INT8 量化模型的输出带 scale 和 zero point，
  `rknn_outputs_get` 在请求时会转成 float——解码层拿到的直接是 float，不用自己算 scale；
- **版本约束**：`librknnrt.so`（板子上是 **v2.3.2**，由 `scripts/setup-npu.sh` 装）**不能低于
  转换模型用的 rknn-toolkit2 版本**，否则 `rknn_init` 失败且无解释（`Cargo.toml` L34-42
  有这条约束的 pin）。

**验证工具 `duck-bench`**（不在 release 里，是测量工具，走 scp；`duck-detect/src/bin/duck-bench.rs`）：

```bash
cargo board --bins -p duck-detect     # 交叉编译（§4.3 会讲 cargo board 是什么）
scp target/aarch64-unknown-linux-gnu/release/duck-bench radxa@<robot>:/var/tmp/
scp <the>.rknn radxa@<robot>:/var/tmp/duck.rknn
scp -r datasets/raw/<a-session> radxa@<robot>:/var/tmp/frames

/var/tmp/duck-bench --model /var/tmp/duck.rknn --frames /var/tmp/frames
```

它按顺序回答三个问题：**能跑吗 → 还认鸭子吗 → 花多少钱**（延迟分位数 + 本进程 CPU）。

**量化模型的第一个坑——阈值：** 量化模型的分数在**自己的尺度**上，float 模型的 0.5
不是它的 0.5。一跑检测不到东西，先试 `--threshold 0.2`，不要急于怀疑转换出错。

**实测数字**（Radxa ZERO 3 上，2 Hz 节奏，来自 npu-bringup 文档）：

| 项目 | 数值 |
| --- | --- |
| driver / runtime | 0.9.8 / 2.3.2 |
| 延迟 p50 / p95 | 25.7 ms / 58.4 ms |
| 每帧 CPU（含 letterbox 缩放） | 20.7 ms |
| 满载结束时 SoC 温度 | 63 °C |

> 💡 **letterbox（1280×720 → 320×320 缩放）在 CPU 上跑**，CPU 数字不是纯 NPU 的代价。
> 用 NPU 的意义是**不占用 robotd 的 50 Hz 循环**，这个目标要在测量后确认。

### 2.8 两条模型链路对照表

| | 策略（policy） | 检测器（detector） |
| --- | --- | --- |
| 训练仓 | `microduck_rl`（PPO/MuJoCo） | `duck_detector`（YOLO，外部仓） |
| 转换 | 不需要（CPU 直接跑 ONNX） | `to_rknn.py` INT8 量化（NPU 跑 RKNN） |
| 板载格式 | `.onnx` | `.rknn` + `.onnx`（CPU 兜底） |
| 发布地 | `<user>/microduck-<name>` 或官方策略集 | `pollen-robotics/microduck-duck-detector` |
| 上板命令 | `robotctl policy add/load/update` | `robotctl duck-detector update` |
| 加载校验 | `obs_len`/`action_len`/`model_api`/`robot.model` | 形状 + 阈值 |
| 谁在跑 | `robotd`（50 Hz 循环） | `mediad`（摄像头侧） |
| 更新后重启 | 不重启（槽位重新加载） | 重启`mediad` |

## 3. 硬件调试：从体检到动起来

> ⚠️ **当前状态（2026-09）**：参考板尚未接上舵机、摄像头与 ToF HAT。本节按"硬件到手后的完整流程"组织，每一步都标注 **【无需硬件】** 还是 **【需硬件】**。硬件到齐后可直接照做；不依赖硬件的部分（总线体检、日志、排障习惯）建议先练手。
>
> 核心思想只有一个：**板上的一切硬件都由 7 个 daemon 包了一层接口，始终从 `robotctl` 这一侧观察和操作，不要绕过 daemon 直接摸硬件。** 绕过了，下一层就是"为什么它不理我"的无底洞。

### 3.0 硬件地图：这条鸭子身上有什么

> 📌 **参考板实测基线（2026-09-18，SSH 上板逐项核实，非照抄官方文档）**：
> 系统是 **Radxa OS 的 KDE 桌面版镜像**（`/etc/os-release` = `Debian GNU/Linux 12 (bookworm)`；`/proc/device-tree/model` = `Radxa ZERO 3`），
> 内核 **6.1.84-10-rk2410-nocsf**，桌面相关包已装 `kde-plasma-desktop`、`sddm`、`radxa-desktop-branding`；
> 内存 2 GB（`free -m` 1978 MB）；Wi-Fi/BT 芯片 **AIC8800**（不是 Armbian——官方 `media-bringup.md` 里那些
> Armbian 专属的坑在参考板上不存在，下文凡涉及都会区分）。
> 当前已启用的 overlay（`/boot/extlinux/extlinux.conf` 的 `fdtoverlays` 行）是
> `rk3568-i2c4-m0.dtbo`、`rk3568-npu-enable.dtbo`、`rk3568-uart2-m0.dtbo`；而 `/boot/dtbo/` 里的
> `rk3568-i2c3-m0.dtbo` 是 `.disabled`。
>
> 总线上"谁挂在哪儿"的实测快照：`/dev/i2c-*` 只有 **0 / 3 / 4 / 6**——i2c-0 上是 PMIC `rk817 @0x20`
> 与 `syr827 @0x40`，i2c-3 上是 Type-C 控制器 `fusb302 @0x22`，i2c-6 是 HDMI DDC；**`/dev/i2c-4` 当前没有从机应答**
> （HAT 未接）。另有 udev 建立的稳定别名 `/dev/i2c-pihat -> i2c-3`（规则 `/etc/udev/rules.d/99-robot-i2c-pihat.rules`）。

```text
                    Radxa ZERO 3W（参考板，Radxa OS / Debian 12）
   ┌──────────────────────────────────────────────────────────────┐
   │  /dev/ttyS2  ←── Dynamixel UART（protocol 2.0，唯一电机总线）│
   │  /dev/i2c-4  ←── HAT 上的 ToF（VL53L5/8CX，8×8 深度矩阵）    │
   │  CSI-2 MIPI  ←── 摄像头（22-pin 座；overlay 见 §3.5）        │
   │  I2S / codec ←── 音频（喇叭 + 麦克风，HAT 未接时只有 HDMI 声）│
   │  NPU ←─ /dev/dri/by-path/platform-fde40000.npu-render        │
   │       （实测指向 renderD129；renderD128 是 display，见下注） │
   └──────────────────────────────────────────────────────────────┘
             │ 一条总线上的两个"人"
             ▼
   15 × Dynamixel 协议舵机 + IMU 板（id 200，走 imu_to_dxl）
   左腿 20–24 · 右腿 10–14 · 头/脖子/嘴 30–34（robotd-design.md §1.1 官方布局）
   · 同一条 UART、同一个 protocol 2.0、同一次 sync_read 批量读回
   · 舵机具体型号由机器人配置决定：参考板使用的是 HD1910（官方鸭子是 XL330，同协议不同电机）
   · 机器人没有第二根电机总线，也没用 DXL 之外的协议（docs/design/robotd-design.md §1.1）
```

```mermaid
flowchart LR
    MCU["Radxa ZERO 3W 主控"]
    MCU --> UART["UART2 /dev/ttyS2（半双工换向后）"]
    UART --> SERVO["15 × Dynamixel 舵机（左腿 20–24 / 右腿 10–14 / 头颈嘴 30–34）"]
    UART --> IMU["IMU 板 id 200（imu_to_dxl，与舵机共用串口）"]
    MCU --> I2C4["i2c-4（overlay 已启用）"]
    I2C4 --> CODEC["TLV320AIC3104 codec（HAT 未接）"]
    I2C4 --> TOF["ToF VL53L5/8CX，8×8 深度矩阵（HAT 未接）"]
    MCU --> I2C3["i2c-3（基础总线，udev 别名 /dev/i2c-pihat）"]
    I2C3 --> FUSB["Type-C 控制器 fusb302 @0x22"]
    MCU --> NPU["NPU /dev/dri/by-path/platform-fde40000.npu-render"]
    MCU --> CSI["MIPI CSI-2（22-pin / 0.5 mm）"]
    CSI --> CAM["IMX219 摄像头（未启用）"]
    MCU --> I2S["I²S / 音频"]
    I2S --> HDMI["rockchip-hdmi 声卡（HAT 未接时唯一一张）"]
```

> **图 5**：Radxa ZERO 3W 主控到各总线与外设的连接关系，括号内为参考板实测的启用与接线状态。

> ⚠️ **NPU 设备节点以 by-path 为准，别记编号**。参考板实测
> `/dev/dri/by-path/`：`platform-fde40000.npu-render → renderD129`（NPU）、
> `platform-display-subsystem-render → renderD128`（显示）、
> `platform-fde60000.gpu-render → renderD130`（GPU）。renderD 编号按驱动 probe
> 顺序分配，换内核/配置可能挪位；librknnrt 自己枚举找 NPU，稳定标识是 by-path。
> （早期排查笔记里"NPU=renderD128"的说法与本次实测不符，以 by-path 为准。）

**舵机 ID 布局是官方写死的**，不是随便编的号（`docs/design/robotd-design.md` L35-37）：

| ID | 位置 | 数量 |
| --- | --- | ---- |
| 200 | `imu_to_dxl`（IMU 板，伪装成"舵机"） | 1 |
| 20–24 | 左腿（hip_yaw → ankle 五关节） | 5 |
| 10–14 | 右腿（同上） | 5 |
| 30–34 | 头 / 脖子 / 嘴 | 5 |

为什么 IMU 能和舵机挂同一条线？因为 Dynamixel 是地址寻址的菊花链：每帧带目标 id，
主控广播、目标应答。IMU 板把自己伪装成一个 id=200 的"舵机"（协议层）挂进来，
`robotd` 一次 `sync_read` 就把 15 个舵机 + IMU 的数据全拿回来了（IMU 排在 id 向量第一个，
先于舵机爆回应）。这条链是**机器人唯一的运动感知来源**，所以排查顺序永远是：总线 → robotd → 上层。

**主控的接口是怎么分给鸭子的**（OpenMicroDuck `docs/main_controller.md` §4，ZERO 3W 的 40-pin 引出）：

| 接口 | 40-pin 位置 | 鸭子拿来做什么 |
| --- | --- | --- |
| **UART2** | 40-pin 引出 | HAT 半双工换向后 → 舵机总线 +`imu_to_dxl`（id 200） |
| **I²C（实测 I²C4 M0）** | 40-pin 的 3 / 5 | HAT 上 codec、ToF。**参考板 `fdtoverlays` 启的是 `rk3568-i2c4-m0` → `/dev/i2c-4`**（`i2cdetect -y 4`，实测总线在、无设备因 HAT 未接）。⚠️ OpenMicroDuck `main_controller.md` 原文写"I²C3 M0"，与参考板的 Radxa 设备树不符——以板子实测的 i2c-4 为准；原厂该控制器另一复用给了 USB-C PD，改到 M0 后失去 PD 协商，5 V 充电仍可用 |
| **MIPI CSI** | 22-pin、0.5 mm 间距、4-lane 座 | **IMX219**（8MP，77° 裸模组；选购见 §3.0.2，overlay 见 §3.5） |
| **I²S** | 40-pin | HAT 上 TLV320AIC3104 音频 codec（HAT 未接时 `cat /proc/asound/cards` 只有 `rockchip-hdmi` 一张卡，见 §3.6） |
| **Wi-Fi / BT** | 板载 | `configd` / `btd`，不经过 HAT |

> ⚠️ **UART2 要防 `serial-getty` 抢端口**：系统可能默认在 UART2 开 `serial-getty`
> （登录终端），一个 `agetty` 占着 `/dev/ttyS2`，**所有舵机就全看不见了**。
> `scripts/setup-board.sh` 会 mask 这个 unit——**参考板已实测处理到位**：
> `systemctl is-enabled serial-getty@ttyS2` = `masked`（指向 `/dev/null`，2026-09-15
> setup-board 时做的）。官方文档把它叫"Armbian 默认坑"，但机制与发行版无关，Radxa OS
> 一样要查。若再出现"突然全不认舵机"，先 `sudo fuser -v /dev/ttyS2` 看是不是 agetty
> 又回来了；手工处理：`sudo systemctl mask serial-getty@ttyS2`（robotd-design.md §1.1）。

**总线的"运行参数"是启动时写进舵机 EEPROM 的**（robotd-design.md §1.1、§2.1）——不是默认值：

| 寄存器 | 值 | 为什么 |
| --- | --- | --- |
| `baud_rate` | **3**（= 1 000 000 bps） | 50 Hz 环一拍要读写 16 个设备，波特率低于 1 Mbps 拍预算就爆 |
| `return_delay_time` | 0 | XL330 出厂 250 = 每设备 500 µs 换向，16 个设备约 8 ms = 拍预算的 40%，必须清零 |
| `pwm_slope` | 255 | 位置环斜率，防电流尖峰 |
| `shutdown` | 52 | 错误锁存掩码：过载 + 过热 + 输入电压故障（谁触发谁锁住，必须 reboot 才清） |

> 💡 理解**换向（turnaround）**：Dynamixel 是半双工总线，一个设备答完才能轮下一个。
> 每个设备默认回包前等 500 µs，15 个舵机 + IMU 串下来一拍就吃掉 8 ms（20 ms 拍的 40%）。
> 把 `return_delay_time` 清零，就是把这 8 ms 还回去——所以"init 慢"和"一拍 50 Hz"的账，
> 都在这几个寄存器里。

### 3.0.1 舵机选型：HD1910 与官方 XL330

> 本节内容主要来自 OpenMicroDuck 仓库的 `docs/servo.md`（选型逻辑）、`docs/bom.md`（采购）
> 与 `docs/structure.md`（结构差异）。先记住一句话：
> **"总线说 Dynamixel 话" ≠ "电机是 ROBOTIS 原厂"。**

官方 Microduck 的 BOM 是 **ROBOTIS Dynamixel XL330-M288-T**（18 g、288.4:1 减速比、
堵转 0.60 N·m @ 6 V、Dynamixel Protocol 2.0）。参考板改用 **飞特 Feetech HD-1910-C001**，
OpenMicroDuck 的 3D 结构就是**按这颗舵机优化**的（`docs/structure.md`：HD1910 拆掉副舵盘后是
**突起**的，XL330 是**凹陷**的，头部/躯干/胯/腿/脚都为此改过——**不要拿 XL330 的结构件硬装 HD1910**）。

两者**协议层兼容**：HD-1910 是半双工 8N1 的"飞特数字包"，总线上按 XL330 的协议/寄存器工作
（1 Mbps、`baud_rate=3`），所以 robotd 不用改一行代码。**但电机本身不是同一颗——
换型号必须重训策略**（§2 里所有训练/彩排命令带 `--motor hd1910`，就是这个原因）。

**HD-1910-C001 关键规格**（飞特规格书 A/0，2026-09-07，`OpenMicroDuck/hardware_spec/servo/`）：

| 项目 | HD-1910-C001 | 对照 XL330-M288-T |
| --- | --- | --- |
| 重量 / 尺寸 | 21 ± 2 g / 20 × 34 × 23 mm（含舵盘） | 18 g / 20 × 34 × 23 mm |
| 减速比 | **320 : 1** | 288.4 : 1 |
| 工作电压 | **4–8.4 V**（6 V 为标定点） | 3.7–6.0 V（推荐 5 V） |
| 堵转扭矩 | **12 kg·cm**（1.18 N·m）@ 6 V | 6.1 kg·cm（0.60 N·m）@ 6 V |
| 额定扭矩 | **3 kg·cm** @ 6 V | 手册未给 |
| 空载转速 | 92 rpm @ 6 V | 123 rpm @ 6 V |
| 电流 @ 6 V | 待机 20 mA / 空载 ≤180 mA / 额定 690 mA / 堵转 1.6 A | 17 mA / — / — / 1.74 A |
| 编码器 | 12-bit 磁编码 | 12-bit 绝对式（AS5601） |
| 电机 / 齿轮 | 空心杯 / 金属齿 | 有芯 / 工程塑料 |
| 协议 | 半双工 8N1，飞特数字包（总线按 XL330 协议跑） | Dynamixel Protocol 2.0 |
| 恒力模式 | 模式 2 恒流；默认模式 4（PD 位置） | Mode 0 电流 / Mode 5 电流限制位置 |
| ID 范围 | 0–253（出厂 ID 1） | 0–252 |
| 针序（AMP2.0-3P） | **1=Signal / 2=Vcc / 3=GND** | JST 3P：**1=GND / 2=Vcc / 3=DATA** |
| 零售价（2026-09） | 预售**¥123** | $23.90–$27.49 / ¥95–¥238 |

HD-1910 在 4.8 / 6 / 7.4 V 的完整电气点（规格书 §5）：空载 73 / 92 / 113 rpm；堵转 9 / 12 / 15 kg·cm；
额定 2.2 / 3 / 3.7 kg·cm；堵转电流 1.2 / 1.6 / 2 A。**Kt = 7.5 kg·cm/A**（力矩电流比，BAM 标定用）。

**四个必须记的差异**（对照表之外的坑）：

1. **针序相反，别直插**：HD-1910 是 **1=Signal / 3=GND**，与 XL330 和飞特 HL-2915
   （**1=GND / 3=Signal**）相反。做转接线/HAT 前先核对针序，插反轻则不认、重则烧舵机板。
   OpenMicroDuck 桌面调试阶段专门有一根 **PH2.0 转 5264 3P** 转接线（`docs/bom.md`），
   就是给"外置 URT2（5264 口）→ HD-1910（AMP2.0-3P 口）"用的。
2. **电压范围宽，但别超 8.4 V**：HD-1910 走 4–8.4 V，过压保护阈值 10 V。2S 锂电（7.4 V）
   直供在范围内；供电轨的 MOS / 连接器电流预算按 15 路额定电流（690 mA × 15 ≈ 10 A 峰值预算）算。
3. **扭矩几乎翻倍，结构是适配过的**：6 V 堵转 12 kg·cm ≈ XL330 的两倍，额定 3 kg·cm。
   OpenMicroDuck 的结构/装配件（`cad/`）已按 HD-1910 调好，别混用 XL330 零件。
4. **换型号 = 重训策略**：官方 9 个 ONNX 是给 XL330 的 BAM M6 执行器模型训的，不能当
   bit-exact 用到 HD-1910 上（servo.md §1 引言：*换执行器之后，官方 9 个 ONNX 不能当即插即用步态*）。
   训练/彩排命令统一带 `--motor hd1910`（§2.1 ③、§2.3），就是让 BAM 用 HD-1910 的参数
   （`microduck_rl/vendor/bam/bam/params/hd1910/*.json`）。

### 3.0.2 采购清单：硬件到手前先对一遍（OpenMicroDuck BOM）

OpenMicroDuck 把采购分成**两个阶段**（`docs/bom.md`）——**别等所有零件齐了再开工**：

- **桌面调试版**：主控和舵机驱动板**外置**，用电源适配器供电、舵机驱动板直接连 PC，
  先把控制和策略跑通（研发期主力）；
- **整机集成版**：Zero Robot HAT + IMU 转接板 + 电池全部进机体内，装好模型软件成整机。

**共用件**（两个版本都要）：

| 器件 | 型号 | 规格 | 数量 | 备注 |
| --- | --- | --- | ---- | --- |
| 舵机 | 飞特 HD-1910-C001 | 恒力空心杯舵机，4–8.4 V，堵转 12 kg·cm | 15 | 换型号必须重训策略  |
| 主控 | Radxa ZERO 3W | RK3566，2 GB RAM，带 WiFi，无 eMMC，带排针版 | 1 | 系统装在 MicroSD 上 |
| SD 卡 | MicroSD / TF | 64 GB，A2 | 1 | 无 eMMC 时必需 |
| 摄像头 | Sony IMX219（Pi Cam v2 规格） | MIPI FPC 排线，**800 万像素**（3280×2464），77° 标准镜头裸模组 | 1 | CSI 接口，选购细节见下注 |
| 麦克风 / 扬声器 | — | — | — | 料号未定 |

紧固五金（M2/M2.5 自攻螺丝各规格共约 131 颗、轴承 6700K × 3 与 ET2216 × 1）和 3D 打印结构件
（约 40 个零件，推荐 PLA，脚垫可试 TPU-95）详见 `bom.md` 原文，这里不重复。

> 🔩 **轴承怎么买（核对 CAD 模型后给出的结论，数量有一处存疑，先看再下单）**
>
> | 型号 | 规格（内径 × 外径 × 厚） | `bom.md` 写 | CAD 模型实测 | 用途 |
> | --- | --- | --- | --- | --- |
> | **6700K** | **10 × 15 × 3 mm** | 3 | **3** ✅ 对得上 | 左右脚踝等 |
> | **ET2216** | **16 × 22 × 4 mm** | 1 | **11** ❌ 对不上 | 各关节（髋 / 膝 / 颈 / 躯干等） |
>
> - **尺寸已双重确认**：把训练模型 `robot_openmicroduck_groundcontact.xml` 里的两个轴承网格
>   解析出来测量包围盒——`..._default` = 外径 15 × 厚 3（对应 6700K），`..._22x16x4` = 外径 22 × 厚 4
>   （对应 ET2216），与 `bom.md` 的尺寸逐字吻合。
> - ⚠️ **6700K 认准"厚 3"**：市面上最常见的"6700"标准件是 **10×15×4（厚 4）**，而本设计用的是
>   **10×15×3 薄款**。买成 4 mm 会顶到装配面、盖不上盖子——下单时认清 **内10 外15 厚3**。
> - ❗ **ET2216 数量存疑，别直接按 1 个买**：`bom.md` 写 1 个，但 CAD 模型里 16×22×4
>   轴承出现了 **11 次**（躯干 ×2、yaw2roll、bearing_roll、左右髋、左右膝、neck_pitch、
>   yaw_roll_motion ×2），基本是**每个关节一个**。两种可能：`bom.md` 漏写（应为 11），或作者有意
>   换成了别的方案而模型没改。**下单前务必看装配图 / 问作者确认**，宁可按 11 个备料（这种薄壁
>   轴承单价低、多买不心疼），也别只买 1 个装到一半卡住。
> - 复核方法：模型文件
>   `microduck_rl/src/mjlab_microduck/robot/microduck/robot_openmicroduck_groundcontact.xml`
>   里搜 `seeed_bearing`，数 `class="visual"` 的行数即每种轴承的个数。

> 📷 **摄像头怎么下单（基于参考板 2026-09-18 实测给出的结论）**
>
> - **买：IMX219、77°、800 万、裸 FPC 模组（不带桌面三脚架）**，配 **22-pin / 0.5 mm
>   间距** MIPI 排线，长度够从头舱绕到主板。77° 就是 Pi Cam v2 标准镜头，mediad 的
>   采集模式（3280×2464）、rkaiq 3A、180° 倒装翻转全按它调过。
> - **像素纠错**：OpenMicroDuck `bom.md` 原文写"IMX219，500 万像素"是**误写**——
>   IMX219 原生 3280×2464 = **808 万**（Pi Cam v2 就是 8MP）；500 万的是 OV5647
>   （Pi Cam v1，2592×1944），别买错。商品页也佐证：IMX219 款一律标"800 万"。
> - **参考板三道硬件关的实测**：① `/boot/dtbo/` 里有
>   `radxa-zero3-rpi-camera-v2.dtbo`（IMX219）与 `-v1.3`（OV5647）两个 overlay，且**均为 `.disabled`**，
>   `fdtoverlays` 行里也没有 camera → 摄像头当前未启用、未接；
>   ② `/etc/iqfiles/` 里同时有 `imx219_RADXA-CAMERA-8M_default.json` 与
>   `imx219_rpi-camera-v2_default.json`，**没有 IMX519** 的 IQ 文件——所以商品页的
>   "78 度 1600 万 IMX519"直接排除（rkaiq 无校准、无 overlay，起不来）；
>   ③ mediad 的 sensor mode 钉死 IMX219，OV5647 虽有 overlay/iqfile 但官方原话
>   "Only the first has ever been used"，不当小白鼠。
> - **广角款（120°/160°）不推荐**：畸变/鱼眼边缘变形对 320×320 YOLO 检测器减分，且未适配。
> - 收到后验证见 §3.5：overlay 启用后 `dmesg | grep imx219` 应出现
>   `Model ID 0x0219`，并出现十个左右 `/dev/videoN`。

**桌面调试版额外**（研发期必须）：

| 器件 | 型号 | 规格 | 数量 | 原因 |
| --- | --- | --- | ---- | --- |
| IMU 模组 | LSM6DSV16X 模块 | 支持 I2C 和 SPI | 1 | IMU_to_servo 自制板未就绪前，成品模组直接挂主控 I2C/SPI 读陀螺仪/加速度 |
| 舵机转接线 | PH2.0 转 5264 3P | 1 根 PH2.0 3P 接 1 根 5264 3P | 1 | 外置飞特 URT2 口是 5264/AMP-3，HD-1910 是 AMP2.0-3P，**中间必须转接** |
| 舵机驱动板 | 飞特 URT2 串口总线舵机驱动板 | Type-C 接口 | 1 | 桌面调试的总线入口，直接连 PC |
| 舵机电源适配器 | 7.5 V 3A，DC 5.5×2.1 插头，3C 认证 | — | 1 | 给外置 URT2 / 舵机供电 |
| 主控电源适配器 | Type-C PD（5 V 3A 或 5 V 2A） | — | 1 | 主控外置时单独供电 |

**整机集成版额外**：Zero Robot HAT 转接板（40-pin 半双工舵机换向 + 电池配电 + I²C / I²S 外设）、
IMU_to_servo 转接板（板载 LSM6DSV16X，挂在舵机总线上、规划从机 ID 200，对齐官方 50 Hz 契约——
整机里 IMU 与 15 颗舵机同一趟 `sync_read`，不再走主控上的裸 I²C 模组）、
7.4 V 3400 mAh 2S 锂电池组（18650×2，2C 放电，XH2.54 2P 公头）。

### 3.1 硬件体检【无需硬件】：先养成这个习惯

```bash
robotctl health          # 一次性报告：硬件 + 软件 + 网络 + 电量温度
robotctl health --json   # 机器可读，可接脚本；不健康时退出码非 0
```

`health` 是排障第一站：它把"电机总线识别到没有、IMU 读数正不正常、哪个 daemon 没在跑"
一次性摆出来。退出码非 0 可以拿来写检查脚本（比如每分钟跑一次，非 0 就报警）。

```bash
robotctl monitor         # 实时 TUI，看循环的"真实世界"
```

`monitor` 是调试主力，它的版面分别对应这些信息：

| 版面 | 看什么 |
| --- | --- |
| 指令 vs 实际 | 每条腿关节的目标角 vs 传感器实测——**偏差持续 >3° 就是机械/电机问题** |
| IMU 投影重力 | 机器人"以为"自己在往哪倒（跌倒判断的依据） |
| 循环频率 | robotd 是否稳定 50 Hz；掉到 30 Hz 以下先查 CPU 争抢 |
| 电机总线 | 读写耗时、失败次数、电压/温度（每秒采样一次） |
| 电量 / 温度  | 电量与温度趋势，避免在低电量下游走 |

monitor 按键：`q` 退出、`t` 打开 ToF 矩阵、`c` 打开摄像头窗口、`d` 关右侧机器人小图
（终端窄时按 `d`）、`p` 打开手柄输入流。

> 💡 **把「先 health，再 monitor」练成本能。** 这两个命令不碰任何硬件状态、不产生副作用，
> 任何时候都可以跑——这是硬件调试里唯一可以闭眼执行的环节。

### 3.2 舵机总线调试【需硬件】：Dynamixel 链

**先认识三个基本操作**（`robotctl robot …`，全部由 `robotd` 代理执行，因为它独占总线）：

```bash
robotctl robot init              # 给所有关节上电，约 2 秒位置斜坡到 home 姿势
                                 # 会动所有关节！放架子上或扶住（main.rs L437-448）
robotctl robot relax             # 切电，机器人瘫倒——拿起/收纳前先 relax
robotctl robot reboot-motors     # 重启全部舵机（或 reboot-motors 10 20 只重启这两颗）
                                 # 舵机过载/过热进入硬件错误时用它恢复，无需拔电池
                                 # 注意：重启后 torque off，要再 robot init 或按 Start
                                 # ID 布局见 §3.0（10–14 右腿 / 20–24 左腿 / 30–34 头）
```

**三个操作对应三个心智模型：** `init` = 上电并站稳（无策略也能站）；`enable` = 把控制权交给
策略（等于手柄 Start）；`relax` = 放倒。**调试时永远先 `init` 再操作，结束时 `relax`。**

**总线本身的验证**（robotd 没起也能测）：

```bash
sudo systemctl status robotd          # robotd 必须在跑，总线是它独占的
sudo journalctl -u robotd -f          # 看 50 Hz 循环的实时日志：读回失败会在这里报
robotctl monitor                      # 看总线健康栏：读写耗时、失败计数
sudo fuser -v /dev/ttyS2                   # "谁占着总线"？出现 agetty = serial-getty 复活了
                                             # （ttyS2 是 root:dialout，普通用户看不到占用者，要 sudo）
```

**判断"总线活着"的三个信号**（按可靠度排序）：

1. `robotctl health` 的电机总线行显示"识别到 15 个舵机 + IMU"——**最强信号**；
2. `robotctl monitor` 的实际角会跟着指令角动（哪怕有偏差）——说明读和写都通了；
3. `journalctl -u robotd` 里没有周期性 `read failed` / `timeout`——弱信号，有噪音。

**三个常见总线坑：**

- **只报 1 个舵机或一半舵机**：菊花链断点。从头到尾找松动的接插口，`robotctl robot reboot-motors`
  后重看 health（新插上的舵机按顺序重新上链）；
- **某个舵机一直过热/过载（monitor 电压温度栏飘红）**：机械卡死或减速箱锁死，先 `reboot-motors <id>`
  排除固件态，还红就拆下人工转——电机阻转和固件错误的处理完全不同；
- **换过舵机后第一次 init 很慢或报错**：这是**"收养"机制在工作**（robotd-design.md §2.1）——
  新舵机出厂是 **ID 1 / 57 600 baud**，跟总线（ID 布局 / 1 Mbps）都对不上。`robotd` 启动时
  先 ping 15 个期望 ID；**恰好一个没回应**时，就去 1 Mbps、再降到 57 600 找 ID 1，
  找到后把缺失 ID 和 1 Mbps 波特率写进去、重启它、再跑寄存器检查。所以"换舵机后第一次
  init 慢"是正常的收养周期，等 `journalctl -u robotd` 出现稳定循环再继续；**注意只换一颗**
  ——换两颗以上同时缺位，收养逻辑找不到唯一缺失者，会当作总线故障。

### 3.3 IMU【需硬件】：姿势的裁判

IMU 不是独立传感器，它**住在电机总线上**（id 200，`imu_to_dxl`），和舵机一起被
`robotd` 每 tick 读一次（`robotd-design.md` L144-156：50 Hz 循环、每秒读一次电压/温度）。

- **在哪里看**：`robotctl monitor` 的 IMU 投影重力项——三个值接近 (0,0,-1) 表示板子水平；
  明显偏移且跟随晃动，说明 IMU 活着且在正确工作；
- **跌倒判断**：`robotd` 用 IMU 重力投影决定"是否倒地"，所以**校准/安装方向错误会让机器人
  误以为自己在跌倒**——换过 IMU 板或拆过 HAT 后，先看 monitor 的重力方向对不对再启用控制。
- **ToF HAT 上的 IMU 是另一只**（`[head_imu]`，默认**关闭**，`docs/project/tof-on-demand.md`）：
  ```bash
  sudo robotctl configure      # [head_imu] enabled = true 打开，改完需重启 robotd
  tofd --imu                   # 单独会话里读一次 IMU，验证线路（--imu-hz 可调采样率）
  ```

> ⚠️ **注意：IMU 并不走独立的 I²C 总线。** 参考板实测（2026-09-18）：**`/dev/i2c-imu` 不存在**，
> `/etc/udev/rules.d/` 里也只有 `99-robot-i2c-pihat.rules`、没有 IMU 那条规则；而
> `/etc/robot/robotd.toml` 的 `[bus] port = "/dev/ttyS2"` 注释明确写着 15 个舵机与
> `imu_to_dxl` 板**共用这条串口**。因此"IMU 走独立的 `/dev/i2c-imu`（i2c-4、0x6A）"这一说法
> 在参考板上并未落地，排查时不要按它找设备。自查命令：

```bash
ls -l /dev/ttyS2 /dev/i2c-imu /dev/i2c-pihat   # i2c-imu 会报 No such file or directory
systemctl is-enabled serial-getty@ttyS2        # 实测 masked
```

> 💡 两个 IMU 别搞混：**总线上那个（id 200）是控制用的、必须开**；**ToF HAT 上那个是
> 可选的头部 IMU、默认关**。调错对象是新手最常见的"IMU 坏了"误报来源。

### 3.4 ToF【需硬件】：HAT 上的 8×8 深度矩阵

ToF 由独立的 `tofd` 守护进程独占（跟 robotd 独占总线一个道理），它**只发不收**：
把 8×8 深度矩阵写到 `/run/tofd/tof.sock`，谁想用谁读（`architecture.md` L80-89）。

```bash
robotctl monitor        # 按 t 打开 ToF 矩阵，实时看 8×8 深度（越近越亮）
ls -la /run/tofd/       # 确认 tof.sock 在（tofd 活着）
sudo systemctl status tofd
```

**验证顺序**：`tofd` 在跑 → `/run/tofd/tof.sock` 存在 → monitor 按 `t` 有数据 → 拿手在
HAT 上方 5–20 cm 晃动看矩阵响应。前三步通过但没响应，多半是 I2C 地址或接线。

ToF 挂在 HAT 的 I²C 上，参考板对应的是 `/dev/i2c-4`（overlay `rk3568-i2c4-m0` 已启用），
**HAT 未接时该总线扫不到任何从机**（实测 `i2cdetect -y 4` 为空，全总线也扫不到 TLV320 的 0x18 与 ToF），
接上 HAT 后再按上面的顺序验证即可。

**ToF 很费 CPU 的教训**（`tof-on-demand.md` 实测）：depth + head IMU 的采样开销在
Radxa ZERO 3 上不可忽略。**不用头部 IMU 就保持默认关闭**，省一档 CPU 给 robotd。

### 3.5 摄像头【需硬件】：看世界的眼睛

摄像头是"硬件门槛最高"的一环，两个前置条件缺一不可（`docs/project/media-bringup.md`）：

1. **CSI 摄像头必须配设备树 overlay**——不配的话插上也"没有任何反应"：不出现
   `/dev/video*`、dmesg 一片空白，看起来和没接一模一样（rkisp 采集节点只在 sensor
   probe 成功后才出现）。**但启用方式按系统区分，别照抄官方文档的 Armbian 做法**：

   **参考板 Radxa OS（Debian 12，实测）**——overlay 是 `/boot/dtbo/` 里的文件，
   带 `.disabled` 后缀 = 关闭；extlinux.conf 的 `fdtoverlays` 行用**完整路径**引用，
   不存在 Armbian 那种"overlay_prefix 解析、文件名必须镜像成 `rk3568-` 前缀"的问题
   （摄像头 overlay 本名就叫 `radxa-zero3-rpi-camera-v2.dtbo`，**不带 rk3568 前缀**）：

   ```bash
   # ① 去掉 .disabled 后缀启用 overlay（IMX219 / Pi Cam v2）
   sudo mv /boot/dtbo/radxa-zero3-rpi-camera-v2.dtbo.disabled \
           /boot/dtbo/radxa-zero3-rpi-camera-v2.dtbo
   # ② 把完整路径追加到 fdtoverlays 行（与已有的 i2c4/npu/uart2 并列，空格分隔）
   sudo nano /boot/extlinux/extlinux.conf
   #    fdtoverlays  /boot/dtbo/rk3568-i2c4-m0.dtbo ...  /boot/dtbo/radxa-zero3-rpi-camera-v2.dtbo
   # ③ 重新生成引导配置（命令在 /usr/sbin，普通 SSH 的 PATH 可能找不到，用全路径）
   sudo /usr/sbin/u-boot-update
   sudo reboot
   # 不想手工编辑也可以用 Radxa 官方交互工具：sudo rsetup（Hardware peripherals 菜单）
   ```

   > 📎 **官方文档的 Armbian 做法（在 Radxa OS 上不适用，仅备查）**：Armbian 的 overlay 名靠
   > `overlay_prefix=rk3568` 解析，而 Armbian 把文件命名为不带前缀的
   > `radxa-zero3-rpi-camera-v2.dtbo`，所以要先镜像一份带 `rk3568-` 前缀的文件名。
   > Radxa OS 用 fdtoverlays 完整路径直接引用，**不要去改名加前缀**。

   > ⚠️ **未启用时设备节点就是这个样子**：参考板实测（2026-09-18）**`/dev/video0` 不存在**，
   > 只有 `/dev/video-dec0`、`/dev/video-enc0`；`/boot/dtbo/` 里 camera overlay 全是 `.disabled`，
   > `fdtoverlays` 里也没有 camera。看到这个形态即表示摄像头未启用、也未接。

2. `mediad` 必须启用——**没接摄像头时它找不到 `/dev/media*` 会退出、被 systemd 反复拉起、
   每十几秒烧满一核**（部署篇 §7.3 排障表有这条，参考板已把 mediad 停了：
   实测 `systemctl is-enabled mediad` = `disabled`）。接好
   摄像头、配好 overlay 后第一件事就是把它开回来：
   ```bash
   sudo systemctl enable --now mediad
   ```

**验证命令**（接好摄像头后）：

```bash
robotctl health          # [media] 段显示摄像头型号和分辨率为正常
robotctl monitor         # 按 c 打开摄像头窗口
robotctl frame           # 存一帧到本机：机器人视角的一张快照（--quality 可调 JPEG 质量）
# 帧还有一个 HTTP 出口：http://<robot>:8080/frame（mediad 提供，遥控页面用它）
```

**画面质量**：`robotctl configure` 里 `[media]` 段的 `quality`/`resolution` 控制。
**检测器吃的是流不是快照**——`mediad` 先把帧送进 `duck-detect` 推理，再把带框的结果
编码推给远端（这就是 §2.7 的 NPU 链路在流水线里的位置）。

### 3.6 音频【需硬件】：一句话带过

音频 codec（I2S）由 `mediad` 管，麦克风听声音、喇叭发鸭子叫。验证就一句话：
`robotctl monitor` 按 `q` 旁边的声音栏有电平跳动 = 麦克风活着；放个声音文件喇叭响 = 输出活着。
**音频和视频共用 `mediad`**，所以"声音没了"先查 mediad 日志，再查 codec 驱动。

> ⚠️ **HAT 未接时没有独立声卡**：参考板实测（2026-09-18）`/proc/asound/cards` 只有
> `card 0 [rockchiphdmi]`，`aplay -l` 也只有 rockchip-hdmi。也就是说，在接上 HAT 之前
> 看不到 TLV320 codec 声卡，此时"没有音频输出设备"是正常现象，不代表驱动有问题。

### 3.7 常见硬件故障速查表

| 现象 | 先查 | 下一步 |
| --- | --- | --- |
| 电机总线一个舵机都不认 | `robotctl health` 总线行、`journalctl -u robotd` | 查`/dev/ttyS2` 是否存在（`ls /dev/ttyS2`）；没它就是内核/设备树问题 |
| 突然全部舵机不认（之前好好的） | `sudo fuser -v /dev/ttyS2` | 出现`agetty` = serial-getty 复活占了总线；mask 掉（`sudo systemctl mask serial-getty@ttyS2`，参考板实测已 masked） |
| 认到但`read failed` 刷屏 | 总线电压、接线松动 | `robotctl robot reboot-motors`；还不行换线 |
| 只认一半舵机 | 菊花链断点位置 | 从主控往后逐段排查插口；新插上的舵机重新上链 |
| 换上新舵机不认 | 新舵机出厂 ID 1 / 57.6 kbps | 等`robotd` 启动"收养"周期（§3.2），看 `journalctl -u robotd` |
| 某个关节指令 vs 实际偏差大 | monitor 该关节偏差 | 机械卡死/齿轮滑齿，拆下人工转确认 |
| monitor 重力方向不对 | IMU 安装方向 | 重装 IMU 板或改标定，别硬调控制参数 |
| 摄像头黑屏 | overlay 有没有去掉 `.disabled` 并写进 `fdtoverlays` 行（Radxa OS） | `sudo journalctl -u mediad -n 30` 看具体报错；`dmesg \| grep -i imx219` 看 sensor 有没有 probe 到（详见 §3.5，**别再按 Armbian 的 rk3568- 前缀镜像法排查**） |
| ToF 无数据但 tofd 活着 | `/run/tofd/tof.sock`、I2C 地址 | `i2cdetect -y 4` 看设备在不在总线上 |
| 负载莫名飙高 | `systemctl show mediad -p NRestarts` | **没接摄像头时 mediad 崩溃循环**，先 `disable --now`，接好再 enable |

## 4. 软件开发：改代码，推到板子上

> **本节目标**：读完这一节，可以做到**改一行代码、一分钟内在板子上看到它生效**，并且清楚推上去的版本是什么、出问题怎么退回来。整节围绕一个命令：`scripts/dev-push.sh` —— 它就是"从改一行到跑起来"的循环（全文见 `microduck/docs/robot/dev-push.md`）。

### 4.1 代码结构：一个 workspace，七个 daemon

`microduck` 是**单个 Rust workspace**（`microduck/README.md` L92-99），顶层结构：

```text
microduck/
├── Cargo.toml            # workspace；[workspace.metadata.rknpu] pin 了 NPU runtime 版本（§2.7）
├── .cargo/config.toml    # 定义 cargo board（交叉编译别名，§4.3 用）
├── robotctl/             # CLI：调试板子的唯一入口（§3 全用它）
├── duckctl/              # CLI：找板子/SSH/SCP（蓝牙、Wi-Fi 都没网也能找到板子）
├── robotd/               # 50 Hz 控制循环，唯一碰电机的人（改它最危险也最直观）
├── mediad/               # 摄像头/音频/WebRTC 远端
├── updaterd/             # 更新引擎：签名、原子切换、健康门、回滚（§4.3 的 apply、§4.7 的错误表都靠它）
├── configd/              # Wi-Fi、名字、配对
├── padd/                 # 手柄接收
├── btd/                  # 手机蓝牙连接
├── tofd/                 # ToF 8×8 深度矩阵（只发不收）
├── duck-detect/          # 检测器推理绑定（§2.7 讲过 dlopen rknn）
├── duck-ipc-proto/       # 共享协议：JSON-RPC 2.0 NDJSON 方法定义（全部 daemon 通信契约）
├── spaces/               # 示例项目（Python）：hello / vision-demo / policy-shop（§4.5）
├── scripts/              # dev-push.sh、provision-board.sh、seed-*.sh 等板级脚本
└── deploy/               # systemd unit、robotd.toml 部署配置
```

**要改什么先想清楚：** 控制逻辑在 `robotd/src/`（`main.rs` 是主循环，`control.rs` 是策略驱动，`intents.rs` 是意图裁决）；命令契约在 `duck-ipc-proto`；CLI 在 `robotctl/src/`。**"加个命令给鸭子" = 协议加方法 + robotd 实现 + robotctl 接线**，三处都改。

```mermaid
flowchart LR
    WS["microduck：单个 Rust workspace"]
    WS --> RD["robotd：50 Hz 控制循环"]
    WS --> MD["mediad：摄像头/音频/WebRTC 远端"]
    WS --> UD["updaterd：签名、原子切换、健康门、回滚"]
    WS --> CD["configd：Wi-Fi、名字、配对"]
    WS --> PD["padd：手柄接收"]
    WS --> BT["btd：手机蓝牙连接"]
    WS --> TF["tofd：ToF 8×8 深度矩阵（只发不收）"]
    WS --> CL["robotctl / duckctl：CLI"]
    WS --> DD["duck-detect：检测器推理绑定"]
    WS --> IP["duck-ipc-proto：共享协议（JSON-RPC 2.0 NDJSON）"]
    WS --> SP["spaces：示例项目（Python）"]
```

> **图 6**：一个 workspace 中的各 crate 与板上 7 个常驻守护进程的对应关系。

### 4.2 一次性准备（只在第一台板子做一次）

dev-push 的门槛有三件（`microduck/docs/robot/dev-push.md` §Once）：

```bash
# ① 板子必须是 dev board（允许开发密钥）
#    若已按部署篇完成配置：/etc/robot/updater.toml 里 allow_dev_keys=true 且 team.dev.pub 已放好。
#    验证：sudo grep -c 'DEV BOARD' /var/lib/robot/provision.log   # 输出 1 为是

# ② 开发机放开发签名密钥（私钥，板子只留 .pub）
mkdir -p ~/.duck-keys && cp /path/to/team.dev.key ~/.duck-keys/team.dev.key
# 密钥在别处就设：export DUCK_DEV_SECRET_KEY=/path/to/team.dev.key

# ③ 装交叉编译工具链（二选一）
cargo install cargo-zigbuild --locked      # 方式 A：zigbuild + zig
# 或不用装任何东西，每次推加 --docker     # 方式 B：Docker
```

> 💡 **为什么必须签名？** 板子的 `updaterd` 对任何代码一视同仁：验证签名 → 校验哈希 → 检查兼容 → 过健康门。开发密钥签的包，客户板子会**拒收**（跟拒收任意 `--ref` 一样），反过来 dev 板也拒收任何没签名的东西。**没有"临时绕过"，这是设计不是麻烦。**

### 4.3 dev-push 闭环：改一行 → 板子上看到它

```bash
cd ~/microduck

# 方式一：按名字推（板子在蓝牙范围内，会自动找到 IP 并缓存）
scripts/dev-push.sh --name duck-c51b        # 目标板子名，duckctl scan 可查
# 方式二：直接给地址（推荐日常用，绕开蓝牙）
scripts/dev-push.sh radxa@192.168.31.30
# 或设一次环境变量，之后直接跑
export DUCK_BOARD=radxa@192.168.31.30
scripts/dev-push.sh
```

完整输出长这样（每一步都在干什么，一目了然）：

```text
==> building 0.5.1-dev.local.1763400000.g7fc1444 for the board (zigbuild)  # 交叉编译
==> packaging                                                                 # 打成 release 同款包
==> signing with /Users/you/.duck-keys/team.dev.key                          # 签名
==> copying to radxa@192.168.31.30:/home/radxa/duck-sideload                 # 拷上板
==> applying on radxa@192.168.31.30                                          # robotctl update apply --from
==> 0.5.1-dev.local.1763400000.g7fc1444 is live on radxa@192.168.31.30
==> checking every daemon is running it
    current -> 0.5.1-dev.local.1763400000.g7fc1444
    [ok] robotd   [ok] configd   [ok] padd   [ok] updaterd   [ok] btd   [ok] mediad   [ok] tofd
```

版本号 `0.5.1-dev.local.<时间戳>.<commit>`：**每次推送带时间戳，两次推送同一棵 dirty 树不会撞车**。板子上确认与回退：

```bash
robotctl version                        # 板上每个 daemon 实际跑的版本
sudo robotctl update rollback daemon    # 手动回退到上一个 release（目的性回退就这个命令）
```

**三个常用变体：**

```bash
scripts/dev-push.sh --dry-run radxa@192.168.31.30
# 干跑：构建/签名/拷贝/校验全做，只差最后"切换 current"。板子什么都不动。推前必用。

scripts/dev-push.sh --docker radxa@192.168.31.30
# 开发机没有 zig 时用 Docker 构建（更慢，但零工具链要求）

scripts/dev-push.sh --bootstrap radxa@192.168.31.30
# 只用于板子版本 < 0.5.0 的第一次推（老 updaterd 没有 apply --from 的 API）。
# 会停 robotd 并放弃健康门——正常情况下绝不用。
```

**只看代码是否能在板子上编译（不推）：**

```bash
cargo board --bins        # = cargo zigbuild，用板子 target + glibc floor（.cargo/config.toml 定义）
```

```mermaid
sequenceDiagram
    participant Dev as 开发机
    participant Build as 交叉编译
    participant Sign as 打包签名
    participant Board as 板子
    participant UD as updaterd

    Dev->>Build: scripts/dev-push.sh
    Build->>Sign: cargo board --bins 交叉编译
    Sign->>Board: 拷贝到 ~/duck-sideload
    Board->>UD: robotctl update apply --from
    UD->>UD: 验证签名、校验哈希、检查兼容
    UD->>Board: 原子切换 current
    Board->>UD: 健康门检查
    alt 健康门通过
        UD-->>Dev: 新版本生效，各 daemon 均运行它
    else 健康门未通过
        UD->>UD: 自动回滚到上一个 release
        UD-->>Dev: 回滚完成
    end
```

> **图 7**：dev-push 的完整时序——交叉编译、打包签名、推送到板子、`updaterd` 原子切换，以及健康门通过与否的两条分支。

### 4.4 第一个真实改动：加一条"被摸"日志

找一处真实代码，把 debug 级别提到 info，推上去就能在 `journalctl` 里看到。位置：`robotd/src/main.rs` L2171-2182（抚摸检测事件处理）：

```rust
pet_detect::PettingEvent::Start => {
    let calm = !safety.fallen() && controller.as_ref().is_none_or(|c| !c.busy());
    if calm {
        tracing::info!("petting started");
        voice.play("coo", false);
    } else {
        tracing::debug!("petting detected (ignored: busy or down)");
        // 👇 第一行改动：改成 info，这样不用开 debug 就能在日志里看到"被摸但忙"的事件
        // tracing::info!("petting detected (ignored: busy or down)");
    }
}
```

改完推上去：

```bash
ssh radxa@192.168.31.30 'journalctl -f -u robotd'   # 开一个窗口盯日志（推之前开好）
scripts/dev-push.sh radxa@192.168.31.30             # 另一台终端推
# 等板上出现 "[ok] robotd"，去摸摸摄像头/ToF（pet_detect 用它们感知）
# journalctl 里出现 "petting detected (ignored: busy or down)" 即改动已在板上运行
```

> 📖 这条改动被选中，理由有三：**位置真实**、**改动最小**（一行）、**验证直观**（摸一下就有日志）。第一次 dev-push 用它建立"代码确实在板子上跑"的信心，比任何理论都强。

### 4.5 示例项目：spaces/ 里有什么

`spaces/` 是**独立的小项目**（不是 workspace 的一部分），演示"用现成接口拼功能"，全部是 Python、用 `uv` 跑。

**① policy-shop —— 策略商店**（`spaces/policy-shop/app.py` L13-16 定义了它依赖的四个调用）：

```text
policy.fetch    {repo, file}   → updaterd 下载并读 manifest      （板上用 robotctl policy add 等价）
robot.setSkill  {name, path…}  → robotd 写入技能条目并重读技能
robot.policies                 → 重载成功了吗？change_error 字段说"不"及原因
robot.do        {skill}        → 跑它
```

本地跑：

```bash
cd spaces/policy-shop
uv venv && uv pip install -r requirements.txt
export DUCK_HOST=192.168.31.30     # 板子 IP
export HF_TOKEN=hf_xxx             # 读 HF 公共仓只需要一个真 token
uv run app.py
```

界面上选一个策略 → 点 install → 点 run：上面四个调用按顺序各来一次。**这是"客户端怎么调鸭子"的最短教材**——四个调用就是 §2.5 那些 `robotctl policy …` 命令的底层方法名。

**② vision-demo —— 视觉流**：`DUCK_RECEIVER` 指向机器人摄像头帧的接收端，演示"不用板子也能看它看到什么"。跑法同样是 `uv run app.py`（`microduck/README.md` L81-98）。

**③ hello —— 最小演示**：最小可跑的"连上机器人 + 说句话"样板，看目录 README 即可。

> 💡 **spaces 和 daemon 的关系：** daemon 是板子上常驻的系统软件（Rust），spaces 是 PC/手机上的应用（Python）。**鸭子只提供 JSON-RPC 接口，怎么拼由应用决定。** 想加"遥控页面""自动投喂""语音对话"，都是在 spaces 这个层次做。

### 4.6 调试三板斧（按顺序用）

```bash
# ① 盯 daemon 日志（推代码前先开好）
ssh radxa@192.168.31.30 'journalctl -f -u robotd -u configd -u btd -u padd'
ssh radxa@192.168.31.30 'journalctl -f -u updaterd'    # 推更新时盯这个：每阶段、健康门、重启
# panic 会带完整 backtrace——发布版二进制不剥离符号，帧名都在

# ② 要 debug 级别的日志：drop-in 覆盖 RUST_LOG（默认 info）
sudo mkdir -p /etc/systemd/system/robotd.service.d
sudo tee /etc/systemd/system/robotd.service.d/log.conf > /dev/null <<'EOF'
[Service]
Environment=RUST_LOG=debug
EOF
sudo systemctl daemon-reload && sudo systemctl restart robotd
# drop-in 在 /etc 下，能挺过所有后续推送。调完删掉 + daemon-reload 即复原。

# ③ 问板子"你是谁、什么版本、健不健康"
robotctl health && robotctl version
```

### 4.7 dev-push 常见错误速查

下表全部来自 `microduck/docs/robot/dev-push.md` 的 §When it does not work。

| 报错 | 真实含义 | 处理 |
| --- | --- | --- |
| `no dev signing key at ...` | 板子拒收未签名产物 | 放好 `team.dev.key`，或设 `DUCK_DEV_SECRET_KEY` |
| `signature did not verify against any of N usable trusted key(s)` | **板子不是 dev board**（不是包坏了） | `grep -c 'DEV BOARD' /var/lib/robot/provision.log` = 0 就走 `install-dev.md` 补配置 |
| `apply failed (exit 2)` + API mismatch | 板子版本太老，没有 apply --from | 用一次 `--bootstrap`，之后恢复正常 |
| `preflight check failed: SideloadDir ... not there` | 包放在 `/tmp`/`/var/tmp` 下 | `updaterd` 有 `PrivateTmp=yes`，看不到该拷贝；换 `~/duck-sideload` 等路径 |
| `could not reach <name> over Bluetooth` | 名字解析不到地址 | `duckctl scan` 看板子在不在；直接给地址 `radxa@IP` 绕开蓝牙 |
| ssh 重刷后连不上 | 板子重新生成了 host key | `./scripts/provision-board.sh radxa@IP --forget-host-key` |
| `is live but not everything is running it` | 交换成功、健康门过了，但某 daemon 还在旧版 | `robotctl health` 看 units 块；`journalctl -u updaterd -b` |
| libudev 链接错误（重刷后） | 缓存的 libudev 拷贝过期 | `rm -rf ~/.cache/duck-cross/aarch64`，下次推送重新抓 |

## 5. 端到端演练：给鸭子加一个"被摸会回应"的行为

> 把三块内容串成一个完整功能。演练分成"无需硬件"与"需硬件"两段：前者无需硬件即可完成，后者需接上硬件再收尾。每个阶段结束都有明确的"过关"标准——不过关不进下一阶段。

**目标功能**：摸鸭子（ToF 近距离手势 / 摄像头识别），它发出一声"咕"并做个小动作。

### 阶段 0：摸底【无需硬件】（10 分钟）

```bash
robotctl health                       # 板子健康吗？哪个 daemon 没跑？
robotctl version                      # 板上 daemon 版本？
ssh radxa@192.168.31.30 'ls -l /opt/robot/policies/current /opt/robot/detector/current'
```

过关标准：health 全绿（mediad 无摄像头是预期状态，不算病）、版本 ≥ 0.5.0、`policies/current → seed-v5`、`detector/current → seed-duck-v1`。

### 阶段 1：在 PC 上走通"训练 → 导出 → 彩排"【无需硬件】（1 小时）

```bash
cd ~/microduck_rl

# 1) 冒烟测试（拦配置错误）
uv run train Mjlab-Velocity-Flat-MicroDuck --env.scene.num-envs 64 --agent.max_iterations 5

# 2) 导出（用官方 checkpoint；--checkpoint <iter> 填冒烟测试实际跑出的轮数）
uv run scripts/export.py Mjlab-Velocity-Flat-MicroDuck --onnx-file my_walk.onnx --checkpoint 5

# 3) CPU 彩排：真推理路径测延迟 + 动作序列
cargo run --release -p duck-control --example policy-rehearsal -- my_walk.onnx > rehearsal.json
cat rehearsal.json | head
```

过关标准：导出无警告、`rehearsal.json` 里 p50 延迟 < 20 ms、动作序列有限值。**不过关就先停在这一步**——调出问题的是配置，不是鸭子。

### 阶段 2：发布 + 上板【无需硬件】

```bash
# 1) 发布到 HF（需要 HF 账号；repo 名必须是 <user>/microduck-<name>）
uv run publish --task Mjlab-Velocity-Flat-MicroDuck --checkpoint 5 \
  --repo <you>/microduck-my-walk --kind perpetual

# 2) 板子上装进 walk 槽位试跑（装到非当前正在跑的位置，安全）
ssh radxa@192.168.31.30
robotctl policy list                                  # 看 7 个槽位
sudo robotctl policy load walk <you>/microduck-my-walk
sudo robotctl policy reset walk                       # 试完放回原样
```

过关标准：`policy load` 返回成功（manifest 校验通过）、`policy list` 里 walk 槽显示该策略名。

> 💡 想省掉第 1 步也行：先 `scp` 把 ONNX 拷到板子，再 `sudo robotctl policy load walk /home/radxa/my_walk.onnx`（local 来源，同样持久生效）。**文件必须真的在板子上**，否则这个路径会被当成 `org/name` 仓库名而报 `is not an org/name repo`（见 §2.5 的判定规则）。发布只在需要"叫名字/绑手柄/分享/版本管理"时才有必要——见 §2.4 开头的分叉说明。

### 阶段 3：接上舵机、摄像头后的收尾【需硬件】

```bash
# 1) 把 mediad 开回来（§3.5：它因未接摄像头处于停用状态）
sudo systemctl enable --now mediad

# 2) 让鸭子站起来
robotctl robot init            # 上电回 home（放架子上！）
robotctl robot enable          # 交给策略（等于手柄 Start）
robotctl monitor               # 观察：能站住吗？指令 vs 实际偏差？

# 3) 触发"被摸"（阶段 2 的 pet 行为已就绪，取决于 pet_detect 配置的感知来源）
#    观察 monitor 的事件行 + journalctl 里的 petting 日志（§4.4）

# 4) 收工
robotctl robot relax           # 切电，收纳
```

过关标准：`init` 后不抽搐、`enable` 后站住超过 10 秒、被摸触发回应、`relax` 干净放倒。

> 🎯 **这套演练的路线图意义：** 阶段 1 验证工具链是否打通、阶段 2 验证模型契约是否正确、阶段 3 验证真机行为。**每一步都能独立验收，卡在哪一步就去哪一节找答案**（阶段 1 → §2.1-2.3，阶段 2 → §2.4-2.5，阶段 3 → §3 + §4）。

## 6. 常见问题速查

**Q1：改完代码不想等整包编译，能不能只推一个文件？**
不能。daemon 是静态编译的 Rust 二进制，任何改动都要重编译 → dev-push。但增量编译约一分钟，
`--dry-run` 先验、再正式推，两分钟一轮。

**Q2：`robotctl policy load walk xxx` 说拒绝，为什么？**
`policy add/load` 在下载前就校验：`obs_len` 必须 61、`action_len` 14、`model_api` ≤ 当前 daemon、
`robot.model` 必须 `microduck`、命令编码必须 `constant`。看报错对应哪条（§2.5 校验规则）。

**Q3：模型怎么才算"部署好了"？**
三条 `current` 链（§2.6）：`/opt/robot/{policies,detector,daemon}/current` 指向目标版本，
且 `robotctl policy list` / `robotctl duck-detector check` 显示已加载。**模型不重启 daemon，代码要重启。**

**Q4：板子没接摄像头，为什么 CPU 负载会飙高？**
mediad 崩溃循环（部署篇 §7.3 排障表 + §3.7）：找不到 `/dev/media*` 退出，systemd 反复拉起。
`sudo systemctl disable --now mediad`，接好摄像头再 enable。

**Q5：dev-push 报"板子不是 dev board"怎么办？**
`grep -c 'DEV BOARD' /var/lib/robot/provision.log` 输出 0 就是。走 `docs/robot/install-dev.md`：
放 `team.dev.pub`、改 `/etc/robot/updater.toml` 的 `allow_dev_keys=true`、重启 `updaterd`。

**Q6：训练导出的 ONNX 在彩排里延迟没问题，上板后还是慢？**
彩排在 PC 上跑（§2.3），板子 CPU 弱很多。上板后用 `robotctl health` 看 CPU、用 NPU 跑检测器
（§2.7），策略推理预算以**板子实测**为准，PC 数字只是下限参考。

**Q7：怎么把鸭子接回自有网络？（IP 变了）**
`duckctl scan` 蓝牙找名字 → `duckctl --name <名字> wifi connect <ssid> --psk <密码>`。
或者板子上 `robotctl system set-name` 改名后走蓝牙（§4.7 错误表）。

**Q8：更新 daemon 后板子失联了，怎么办？**
健康门 + 自动回滚（§4.3）：起不来的 release 会被自动回退。如果连 updaterd 都坏了，
SSH 上板：`sudo robotctl update rollback daemon`。再不行就上板刷机（部署篇兜底）。

## 7. 参考资料索引（按主题）

**概念与架构**

| 想读什么 | 文件 |
| --- | --- |
| 系统总览、7 daemon 职责、通信方式 | `microduck/docs/design/architecture.md` |
| robotd 设计：50 Hz 循环、舵机总线、IMU 读取 | `microduck/docs/design/robotd-design.md` |
| 更新引擎：签名、原子切换、健康门、回滚 | `microduck/docs/design/update-pipeline.md`（如缺看 updaterd 源码） |

**模型**

| 想读什么 | 文件 |
| --- | --- |
| NPU 上板全记录（性能、转换、阈值） | `microduck/docs/project/npu-bringup.md` |
| 策略清单格式（manifest 契约） | `microduck/docs/policy-manifest.md` |
| 循环策略（LSTM、model_api: 2、彩排） | `microduck/docs/recurrent-policies.md` |
| 训练配置 + 命令（HD1910） | `microduck_rl/docs/training_config_velocity_hd1910.md` |
| 训练仓命令与铁律 | `microduck_rl/AGENTS.md` |

**硬件**

| 想读什么 | 文件 |
| --- | --- |
| 板子速查（health/monitor 等全部命令） | `microduck/docs/robot/cheatsheet.md` |
| ToF 上板与 IMU 配置决策 | `microduck/docs/project/tof-on-demand.md` |
| 摄像头/媒体上板（overlay 坑） | `microduck/docs/project/media-bringup.md` |

**开发**

| 想读什么 | 文件 |
| --- | --- |
| dev-push 全流程（本教程 §4 的原文） | `microduck/docs/robot/dev-push.md` |
| 开发板信任机制（dev key） | `microduck/docs/robot/install-dev.md` |
| 找板子/SSH/SCP（蓝牙兜底） | `microduck/docs/robot/duckctl.md` |
| 开发板速查（重启陷阱等） | `microduck/docs/robot/cheatsheet-dev.md` |

**示例项目**

| 项目 | 位置 | 演示 |
| --- | --- | --- |
| hello | `spaces/hello/` | 连上机器人 + 说句话 |
| vision-demo | `spaces/vision-demo/` | 收摄像头帧 |
| policy-shop | `spaces/policy-shop/` | 策略商店四个调用 |

**OpenMicroDuck 资料**（`OpenMicroDuck/docs/`，本教程 §3.0.1/§3.0.2 的参考来源）

| 想读什么 | 文件 |
| --- | --- |
| 舵机选型：XL330 vs HD1910 全对照、波特率、协议 | `docs/servo.md` |
| 采购清单：桌面调试版 / 整机集成版两阶段 BOM | `docs/bom.md` |
| 主控选型：ZERO 3W 接口分配、RK3566、NPU 现状 | `docs/main_controller.md` |
| 结构说明：HD1910 与 XL330 的结构差异、3D 打印优化点 | `docs/structure.md` |
| 硬件规格书（HD-1910 / HL 系列 / ED330） | `hardware_spec/servo/` |
| HD1910 结构 CAD（Bambu Studio 直接打印） | `cad/openmicroduck.3mf` |

---

## 参考来源

| 内容 | 来源 |
| --- | --- |
| Radxa 官方镜像与安装文档 | [https://docs.radxa.com/zero/zero3/download](https://docs.radxa.com/zero/zero3/download) |
| Microduck 上游仓库（守护进程、脚本、release） | [https://github.com/pollen-robotics/microduck](https://github.com/pollen-robotics/microduck) |
| OpenMicroDuck 上游仓库（硬件与文档） | [https://github.com/pollen-robotics/OpenMicroDuck](https://github.com/pollen-robotics/OpenMicroDuck) |
| Hugging Face Hub（策略与检测器模型分发） | [https://huggingface.co](https://huggingface.co) |
| crates.io 国内镜像（板端编译用） | [https://rsproxy.cn](https://rsproxy.cn) |
| ONNX Runtime（板端推理运行时） | [https://github.com/microsoft/onnxruntime](https://github.com/microsoft/onnxruntime) |
| Rockchip RKNN 工具链 | [https://github.com/airockchip/rknn-toolkit2](https://github.com/airockchip/rknn-toolkit2) |

---

## 待核实事项

以下是整理过程中发现的、**源文档前后不一致或可能已过时**的点。为避免擅自改动数字，这里只如实列出，未在正文中修改；实际执行时请以命令输出为准。本节按核实状态分两组：第一组已在参考板上用只读命令核实并回填事实，第二组需要额外硬件或离线资料，暂无法在板上验证。

**已核实（2026-09-18 板端实测）** —— 下列条目已用只读命令在参考板上核实，逐条给出结论、关键回显与用到的命令：

1. **NPU 设备节点编号**：稳定标识应使用 by-path 路径，不要写死编号。用到的命令 `ls -l /dev/dri/by-path/`；关键回显 `platform-fde40000.npu-render -> renderD129`（同目录下 `platform-display-subsystem-render -> renderD128`、`platform-fde60000.gpu-render -> renderD130`）。→ NPU 对应 renderD129，但编号会随枚举变化，脚本中请用 by-path 路径而非固定编号。
2. **I²C 总线与 IMU 拓扑**：用到的命令 `ls /dev/i2c-*`；关键回显只有 0 / 3 / 4 / 6，**没有 i2c-5**。i2c-3 上是 Type-C 控制器 `3-0022 fusb302 [typec_fusb302]`；i2c-0 上是 PMIC `0-0020 rk817 [rk808]` 与 `0-0040 syr827 [fan53555-regulator]`；i2c-6 是 `DesignWare HDMI`（DDC）；i2c-4 无从机。已启用 overlay 为 `rk3568-i2c4-m0.dtbo`（见 `/boot/extlinux/extlinux.conf` 的 `fdtoverlays` 行），而 `rk3568-i2c3-m0.dtbo` 在 `/boot/dtbo/` 里是 `.disabled`。**参考板上不存在 `/dev/i2c-imu`**；`/etc/udev/rules.d/` 只有 `99-robot-i2c-pihat.rules`（生成 `/dev/i2c-pihat -> i2c-3`），而没有 IMU 对应的那条规则。`/etc/robot/robotd.toml` 使用 `port = "/dev/ttyS2"`（`/dev/ttyS2` 存在：`crw-rw---- root dialout 4,66`），其注释说明 15 个舵机与 imu_to_dxl 板共用该串口；`serial-getty@ttyS2` 实测为 `masked`。→ 因此"IMU 走独立 `/dev/i2c-imu`（i2c4、0x6A）"的表述与参考板不符，以实测为准。
3. **摄像头与摄像头 overlay**：用到的命令 `ls /dev/video*`；关键回显 `/dev/video0` 不存在，只有 `/dev/video-dec0`、`/dev/video-enc0`。`/boot/dtbo/` 中 camera overlay（rpi-camera-v2 / radxa-camera-8m）全为 `.disabled`，且 `extlinux` 的 `fdtoverlays` 未含 camera → 摄像头 overlay 未启用（也未接）。`ls /etc/iqfiles/` 只有 imx219 系列（`imx219_RADXA-CAMERA-8M_default.json`、`imx219_rpi-camera-v2_default.json`），**无 IMX519**。
4. **音频**：未接 HAT 时 `cat /proc/asound/cards` 关键回显只有 `card 0 [rockchiphdmi]`，`aplay -l` 同样只有 rockchip-hdmi，**没有 TLV320 codec 声卡**。
5. **eMMC 与 mmcblk 编号**：用到的命令 `lsblk`；关键回显只有 `mmcblk1`（14.6 G microSD，`mmcblk1p1` 16M → `/config`、`mmcblk1p2` 300M → `/boot/efi`、`mmcblk1p3` 14.3G → `/`），**没有 mmcblk0 / mmcblk2**。→ 无 eMMC 的板子上 microSD 即 `mmcblk1`；"有 eMMC 的板子 SD 卡走 mmcblk0"这条因手上没有 eMMC 板而**未验证**。

**仍待核实（需要硬件或离线资料）** —— 下列条目暂无法用板端只读命令验证，原因逐条注明：

1. **轴承数量冲突**：`OpenMicroDuck/docs/bom.md` 写 ET2216 ×1，而 `robot_openmicroduck_groundcontact.xml` 里 16×22×4 出现 11 次。属 CAD/BOM 问题，板子上验不了，下单前需看装配图或向作者确认。
2. **IMX219 像素数**：`OpenMicroDuck/docs/bom.md` 写"500 万"，而 IMX219 官方规格是 800 万（3280×2464）。需实物确认后缀型号。
3. **训练仓文档路径**：训练用的 `microduck_rl` 仓库里 `docs/training_config_velocity_hd1910.md` 与 `AGENTS.md` 的实际路径可能随上游变动，引用前请先在仓库内确认。
4. **上板用 `update-pipeline` 设计文档路径**：文档中引用的 `microduck/docs/design/update-pipeline.md` 在部分版本中缺失，若不存在请直接看 `updaterd` 源码。
5. **性能实测数字的平台标注**：相关数字来自 PC 侧（CPU 彩排）还是板端 NPU，需在正式发布前逐条标注清楚平台，避免读者误读。
6. **麦克风/扬声器料号**：官方链路是"模拟麦克风 → TLV320AIC3104 codec → PAM8406D 功放 → 无源喇叭"，需确认所选麦克风是**模拟输出**（MEMS 或驻极体电容麦），扬声器是**无源小喇叭**（8 Ω / 1–2 W）；不能用 I²S/PDM 数字麦（如 ICS-43434、SPH0645、SPM1423）或带 3.5 mm/USB 的有源音箱。
7. **章节号交叉引用**：部署篇与开发篇之间的章节号交叉引用（如"部署篇 §7.3"）在最终发布前需按两篇的实际编号再核一遍。

---

## 更新日志

| 版本 | 日期 | 变更内容 |
| --- | --- | --- |
| v1.00 | 2026-09-17 | 由内部版整理为对外发布稿：中性化语气、脱敏、重构章节逻辑 |
| v1.01 | 2026-09-18 | ① 正文按对外发布稿体裁重排并补齐 §1–§7 与文末三节；② 新增 **8 张 Mermaid 结构图**（三条链路总览、7 个守护进程、模型链路、彩排双路径、NPU 推理链路、硬件拓扑、workspace 与 daemon 对应、dev-push 时序），并把 §0.1 的 ASCII 路线图改为 Mermaid；③ 按板端只读实测核实并回填硬件事实（I²C 总线与 IMU 拓扑、NPU 设备节点、摄像头与音频枚举、eMMC/mmcblk 编号），「待核实事项」按"已核实 / 仍待核实"分组 |

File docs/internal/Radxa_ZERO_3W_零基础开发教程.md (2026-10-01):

执行

# Radxa ZERO 3W 零基础开发教程：模型部署、硬件调试与软件开发

> 承接《[Radxa_ZERO_3W_零基础部署调试教程.md](./Radxa_ZERO_3W_零基础部署调试教程.md)》。
> 那份教程教你**把软件装上**，这份教程教你**自己造软件**：训练一个模型、把它部署上板、
> 调试舵机和传感器、改一行代码并在一分钟内看到它跑在鸭子上。
>
> 全部命令都来自本仓库（`e:\optiDuck\joyandai\microduck`、`microduck_rl`）的真实脚本和文档，
> 标注了来源文件，可直接跳过去看原文。

---

## 怎么读这份教程

这份教程假设你已经走完部署教程（板子能 SSH、`robotctl 0.13.0` 已装、7 个守护进程在跑）。
如果你的板子还没装好，先回去把部署教程 §7、§8 做完。

它分四块，可以跳着读：

| 想做什么 | 读哪节 |
| --- | --- |
| 想先搞清楚"鸭子系统到底怎么长在一起的" | §1 |
| 想训练/部署一个自己的策略或检测模型 | §2（全链路） |
| 想调舵机、IMU、ToF、摄像头 | §3 |
| 想改 Rust 代码并推到板子上跑 | §4 |
| 想把上面串起来做一个完整小功能 | §5（端到端演练） |

**三块代码、三个仓库**，先记在脑子里：

| 仓库 | 本地路径 | 干什么 |
| --- | --- | --- |
| `microduck` | `e:\optiDuck\joyandai\microduck` | **上板软件栈**：7 个 Rust daemon、`robotctl`/`duckctl`、板级脚本。你的开发主要在这里 |
| `microduck_rl` | `e:\optiDuck\joyandai\microduck_rl` | **强化学习训练**：MuJoCo + PPO 训走路/站立/翻跟头，导出 ONNX |
| `duck_detector`（外部） | 在 GitHub/HF 上 | **检测器训练**：YOLO 模型训练 + ONNX→RKNN 转换（不在本地仓库里） |

还有一个"仓库"不是代码：**Hugging Face Hub**。策略（`microduck-*`）、检测器
（`microduck-duck-detector`）都以"文件 + 一个 `manifest.json`"的形式发布在 HF 上，
板子通过 `updaterd` 从 HF 拉取。**模型和策略的更新不经过 daemon 发版**——这是全篇最重要的概念之一。

---

## 🎯 0. 路线图：从"会部署"到"会开发"

先看整张图，心里有数再逐节拆。三条链路，本文各占一节：

```text
                        ┌────────────────────────────────────────────────┐
   模型链路 (§2)        │                                                │
   ┌────────────┐  ┌──────┴──────┐  ┌───────────┐  ┌───────────────────┐ │
   │ 训练       │  │ 导出 ONNX   │  │ 转 RKNN   │  │ 发布到 HF Hub     │ │
   │ microduck_ │ →│ scripts/    │ →│ (检测器)  │→ │ policies /        │ │
   │ rl (PPO)   │  │ export.py   │  │ to_rknn.py│  │ duck-detector     │ │
   └────────────┘  └─────────────┘  └───────────┘  └─────────┬─────────┘ │
                                                          │ updaterd     │
   硬件链路 (§3)                                           ▼             │
   ┌────────────────────────┐        ┌────────────────────────────────┐  │
   │ robotctl health/monitor│        │ /opt/robot/policies/current    │  │
   │ 舵机·IMU·ToF·摄像头    │────────│ /opt/robot/detector/current    │  │
   └────────────────────────┘        └──────────┬─────────────────────┘  │
                                                │ robotd 50 Hz 循环      │
   代码链路 (§4)                                │                        │
   ┌──────────┐  ┌──────────┐  ┌──────────────┐ │                        │
   │ 改代码   │ →│ 交叉编译 │ →│ dev-push.sh  │─│ 打包+签名+apply+健康门  │
   └──────────┘  └──────────┘  └──────────────┘ └────────────────────────┘
```

一句话版本：

- **模型 = 被动数据**（`.onnx` / `.rknn` + `manifest.json`），走 **HF Hub → updaterd** 通道，
  更新**不重启 daemon 之外的任何东西**，随时可以回退；
- **代码 = 主动逻辑**（Rust 二进制 + 板级脚本），走 **dev-push / release** 通道，
  每次替换都要过**签名校验 + 健康门 + 自动回滚**；
- **硬件 = 你调试的对象**，全部以 `robotctl health` / `monitor` 为观测入口。

> 💡 **部署教程讲"装"，这里讲"造"。** 你在部署教程里见过的 `policies/current → seed-v5`、
> `detector/current → seed-duck-v1` 这两个符号链接，就是模型链路的终点——读完 §2 你会知道
> 它们是怎么被填上的、以及如何填上你自己的。

---

## 1. 先建立全局观：这个系统是怎么长在一起的

### 1.1 一张图认识 7 个守护进程

部署教程只让你"装上了"，没讲它们各自是什么。这里补上（来自
`docs/design/architecture.md`）：

```text
  手柄(padd)    手机(btd)    你/SSH(robotctl)   远端(mediad)      GitHub release
     │ BLE         │ BLE          │ ssh             │ WebRTC          │ https
     ▼             ▼              ▼                 ▼                 ▼
  ┌─────┐      ┌─────┐      ┌─────────┐       ┌─────────┐        ┌─────────┐
  │padd │      │ btd │      │ robotctl│       │ mediad  │        │ updaterd│
  └──┬──┘      └──┬──┘      └────┬────┘       └────┬────┘        └────┬────┘
     │            │   JSON-RPC 2.0 · 一行的 NDJSON · unix socket      │
     ▼            ▼            ▼                  ▼                   ▼
  ┌──────────────────────────────────────────────────────────────────────┐
  │  robotd（50 Hz 控制循环，唯一能碰电机的人）   configd（Wi-Fi/名字/配对）│
  │  tofd（ToF 8×8 深度矩阵，只发不收）                                  │
  └──────────────────────────────────────────────────────────────────────┘
                          │ 一条 Dynamixel UART（/dev/ttyS2）
                          ▼
              15 个舵机 + IMU（id 200，你的鸭子为 HD1910）
```

**三个必须记住的硬规则**（后面调试全靠它们）：

1. **`robotd` 是唯一能命令电机的人。** 其他人只能发"意图"（走多快、看哪里、站起来），安全性由 `robotd` 裁决。所以舵机总线出问题，先怀疑 `robotd`。
2. **`configd` / `updaterd` / `btd` 不依赖 `robotd`。** 机器人控制循环挂了，你还能改 Wi-Fi、更新、回滚——这是"永不砖"的根基。
3. **服务和数据分两条路：** 命令/状态走 unix socket JSON-RPC（控制面），视频/音频帧**绝不**走 socket（数据面）。所以"摄像头画面卡了"和"电机不动了"永远是两个问题。

### 1.2 两个必须分清的词：`slot` 与 `skill`、`policy` 与 `detector`

| 词 | 意思 | 例子 |
| --- | --- | --- |
| **slot（槽位）** | 机器人**默认**跑什么：7 个固定槽位 `walk`/`stand`/`sitstand`/`ground_pick`/`kick_left`/`kick_right`/`roulade` | `walk` 槽装走路步态 |
| **skill（技能）** | 机器人**被要求时**跑什么：一次性的动作，跑完自己回去 | 鞠躬`polite-bow`、前滚翻 `roulade` |
| **policy（策略）** | 从 RL 训练出的`obs[1,61] → actions[1,14]` 的 ONNX 模型 | `walk.onnx` |
| **detector（检测器）** | 从图像训练出的目标检测模型（YOLO），输入 320×320 帧，输出 2100 个候选框 | `duck_detect.rknn`（NPU）/ `.onnx`（CPU 兜底） |

```text
robotctl policy list   # 看 7 个槽位 + 已装的 skills
robotctl policy add polite-bow <HF repo>   # 加一个技能
robotctl robot do polite-bow               # 让它跑一下
```

> 💡 **`slot` 由配置指向某个模型文件，`skill` 由名字被调用。** 一个策略文件放对地方（槽位/技能），就是"部署"的全部。

### 1.3 三条更新通道：什么走哪条，为什么

| 更新内容 | 通道 | 门槛 | 失败后果 |
| --- | --- | --- | --- |
| **策略 / 检测器模型** | HF Hub →`updaterd`（`robotctl policy update` / `robotctl duck-detector update`） | 只需`manifest.json` 字段合法 | 拒绝安装，现有模型不动 |
| **daemon 代码（发版）** | GitHub release →`robotctl update apply daemon` | 签名 + 健康门 | 自动回滚到上一个 release |
| **你的开发代码** | `dev-push.sh`（用开发密钥签名）→ `robotctl update apply --from` | 开发板 + dev key | 同上，自动回滚 |

**为什么模型单独一条通道？** 因为"换一个策略"和"换一个 daemon"是两种风险等级：
策略文件是数据，`robotd` 每次加载前都会校验形状（`obs_len`/`action_len`/`model_api`/`robot.model`），
错了顶多拒绝加载；而 daemon 二进制是代码，错了可能让板子失联，所以必须过签名 + 健康门 + 回滚。
记住这个分层，后面所有操作都不迷路。

### 1.4 你手上的三板斧（先记住，后面反复用）

```bash
robotctl version          # 每个 daemon 实际跑的版本 vs 已安装版本（先跑这个，别信记忆）
robotctl health           # 硬件 + 软件一份报告；不健康时退出码非 0（可接脚本）
robotctl monitor          # 实时：指令 vs 实际、IMU 重力、循环频率、电量和温度
```

`robotctl monitor` 是调试主力，先记几个键：`q` 退出、`t` 打开 ToF 矩阵、`c` 打开摄像头、
`d` 关掉右侧机器人小图、`p` 打开手柄输入流。终端不够宽时按 `d` 关掉机器人图。

---

## 2. 模型部署：从训练到上板（全链路）

> 目标：这一节结束，你能把一个**自己训出来的模型**（或仓库里已有的模型）放到鸭子上跑起来，
> 并知道每一步卡住时去哪查。全链路五段：

```text
① 训练 (microduck_rl)  →  ② 导出 ONNX  →  ③ 彩排 (CPU)  →  ⑤ 上板+验证
   uv run train            export.py         infer_policy /      robotctl policy /
                                               policy-rehearsal    duck-detector

④ 发布到 HF 是**可选分叉**，插在 ③ 和 ⑤ 之间：
   · 自己板子上用        → 跳过 ④，ONNX 拷到板子直接占槽位（local 来源）
   · 要叫名字/绑手柄/分享 → 先 ④（uv run publish），再装成技能
```

策略和检测器是**两条平行的链**（训练仓不同、转换不同、上板命令不同），分开讲，最后汇总一张对照表。（uv一个包及命令管理器，可以给你的每个命令单独创造一个环境进行运行，速度快、兼容好）

### 2.1 训练一个走路策略（最短路径）

训练仓是 `microduck_rl`，基于 mjlab（MuJoCo + Warp）跑 PPO（rsl_rl）。

mjlab：一个物理机器学习模型，用来分配及观测每次**PyTorch**的结果。一次训练迭代流程如下

1. > **mjlab 重置并并行运行数千个仿真环境**
   > 基于 MuJoCo Warp，在 GPU 上批量步进物理世界。
   >
2. > **策略网络（PyTorch）接收观测，输出动作**
   > 观测是 PyTorch 张量，策略网络也是 PyTorch `nn.Module`，两者共享 GPU 内存，零拷贝。
   >
3. > **mjlab 把动作送入物理引擎，计算新观测和奖励**
   > 奖励、终止条件、课程学习、域随机化都由 mjlab 定义。
   >
4. > **RSL-RL 等算法层用 PyTorch 计算损失和梯度**
   > mjlab 收集 rollout 数据，RSL-RL 调用 PyTorch 的 `autograd` 和 `optimizer` 更新策略参数。
   >
5. > **循环直到策略收敛**
   > mjlab 负责“跑环境”，PyTorch 负责“学参数”。
   >

**你的第一目标是跑通冒烟测试**，不是训出好策略——冒烟测试 1–2 分钟，能拦下约 95% 的配置错误
（这是 `microduck_rl/AGENTS.md` 的原话：*Never launch a long run without one*）。

```bash
cd e:\optiDuck\joyandai\microduck_rl

# 0) 先同步依赖（uv 管理，装好 uv 后）
uv sync

# 1) 冒烟测试（必须先跑；64 envs × 5 iterations，1–2 分钟）
uv run train Mjlab-Velocity-Flat-MicroDuck --env.scene.num-envs 64 --agent.max_iterations 5

# 2) 正式训练（需要 CUDA GPU；8–12 GB 显存用 1024 envs，≥16 GB 用 4096）
uv run train Mjlab-Velocity-Flat-MicroDuck \
  --env.scene.num-envs 1024 \
  --agent.max_iterations 15000

# 3) 续训（从某个 checkpoint 接着跑）
uv run train Mjlab-Velocity-Flat-MicroDuck \
  --env.scene.num-envs 1024 \
  --agent.load-checkpoint logs/rsl_rl/velocity/<run>/model_15000.pt \
  --agent.resume True \
  --agent.max_iterations 30000
```

来源：`docs/training_config_velocity_hd1910.md` §10 训练命令、`microduck_rl/AGENTS.md` Commands。

**训练产物**：`logs/rsl_rl/velocity/<timestamp>/model_<iter>.pt`；
曲线在 wandb 项目 `mjlab_microduck`（本地跑是离线 run：`wandb/offline-run-*`）。

#### 训练前必须懂的三件事（否则训出来的东西上不了板）

**① 观测是 61 维，全系统共享，别动它。** 布局固定：`48 维本体感受 + 13 维命令块 [twist(3), head_pose(4), body_pose(6)]`，顺序固定。新任务只改命令块的含义，**不能删槽位**
（AGENTS.md Invariants 第一条）。全零命令 = 站立——这是部署时的空闲状态，必须显式训练过。

**② 关节布局是 14 个舵机**，`ctrl idx = joint idx`：

```text
0–4   左腿：hip_yaw, hip_roll, hip_pitch, knee, ankle
5–8   脖子/头：neck_pitch, head_pitch, head_yaw, head_roll
9–13  右腿
```

**MDP** 是 **Markov Decision Process** 的缩写，中文叫  **马尔可夫决策过程** 。它是强化学习里描述“智能体如何在一系列状态下做决策”的数学框架。

写 MDP 时永远用 `_servo_joint_ids` / `_servo_joint_pos` 辅助函数取关节下标，
**不要硬编码**（换带被动关节的模型时下标会错位）。

**③ 执行器是 BAM 模型**（电压控制的作动器，摩擦力由执行器自己算）。电机参数按型号分开存：
`microduck_rl/vendor/bam/bam/params/hd1910/*.json`（你的鸭子）/ `hls2909`（另一款）。
训练、彩排命令都要带对应 `--motor hd1910`（§2.3）。`dof_frictionloss` 在 BAM 下是零——
给关节摩擦加 DR **（Domain Randomization，域随机化）**要缩放执行器的 `friction_scale`，否则是静默的无效操作。
**为什么按型号分开？因为换执行器 = 重训策略**：官方 XL330 的 ONNX 是给 XL330 的 BAM M6
执行器模型训的，直接换到 HD1910 上不能 bit-exact 复用（OpenMicroDuck `docs/servo.md` §1），
电机型号写在训练/彩排命令里（`--motor hd1910`），从源头就锁对执行器参数。

#### 训练纪律（少走几个月的弯路）

- **奖励符号：** `microduck_mdp` 里自取负的惩罚项（`*_penalty` / `*_l1` 返回 ≤ 0）要用**正权重**，
  否则双重取负变成"奖励违规"。铁律：每个 `Episode_Reward/<penalty>` 在 wandb 里必须 ≤ 0。
- **预算参考：** 简单一次性动作 ≈ 1000 iterations（4096 envs）；走路等复杂步态 4000–6000。
- **失败先测再改：** 别凭感觉调奖励，先 headless 评估 checkpoint，很多"失败"只是 checkpoint 太早。

> 💡 **当前板子实况：** 板子上 `policies/current → seed-v5` 是官方策略集。你训练的第一步
> 不是替换它，而是先在 PC 上跑通"冒烟 → 导出 → 彩排"，等 §2.3 的彩排通过再谈上板。

### 2.2 导出 ONNX（归一化会被烤进模型）

训练完的 checkpoint 不能直接用，必须走**官方导出器**——它会把观测归一化
（`obs_normalization=True`）**烘焙进 ONNX**。手工转换会丢掉归一化，在仿真里玩看不出问题
（play 时环境会再归一化一次），上了真机才露馅。这是 AGENTS.md 明确警告过的坑。

```bash
# 方式 A：从 wandb run 导出
uv run scripts/export.py Mjlab-Velocity-Flat-MicroDuck --wandb-run-path <entity/project/run_id>

# 方式 B：从本地 checkpoint 导出（最常用）
uv run scripts/export.py Mjlab-Velocity-Flat-MicroDuck \
  --onnx-file walk_hd1910.onnx --checkpoint <iter>
```

例如需要导出以下目录模型：E:\optiDuck\microduck_rl\logs\rsl_rl\velocity\2026-09-15_20-44-58_prebom_resume

实际命令为：

```Shell
# 1) 切到训练仓库根目录（导出器按相对路径找 logs/）
cd E:\optiDuck\microduck_rl

# 2) 导出 model_7750.pt → walk_hd1910.onnx（归一化自动烤进 ONNX）
uv run scripts/export.py Mjlab-Velocity-Flat-MicroDuck `
  --checkpoint-file "E:\optiDuck\microduck_rl\logs\rsl_rl\velocity\2026-09-15_20-44-58_prebom_resume\model_7750.pt" `
  --onnx-file walk_hd1910.onnx

# 3) 确认产物（应显示 walk_hd1910.onnx，约几十 MB）
Get-ChildItem walk_hd1910.onnx | Select-Object Name, Length, LastWriteTime
```

3D演示模型的命令如下：

```Shell
cd E:\optiDuck\microduck_rl

uv run play Mjlab-Velocity-Flat-MicroDuck `
  --checkpoint-file "E:\optiDuck\microduck_rl\logs\rsl_rl\velocity\2026-09-15_20-44-58_prebom_resume\model_7750.pt" `
  --num-envs 1
```

导出实现（`microduck_rl/src/mjlab_microduck/export.py` L251-L269）的核心动作：
`runner.export_policy_to_onnx` 只导出 actor（critic 不上板），把观测归一化的均值/方差写成
ONNX 常量，并把 `model_api`、`obs_len`、`action_len` 等写进 metadata。

**产出契约**（也是板子校验的契约，见 `docs/recurrent-policies.md` 与 `docs/policy-manifest.md`）：

| | 输入 | 输出 |
| --- | --- | --- |
| 前馈模型 | `obs [1, 61]` | `actions [1, 14]` |
| LSTM 模型（`model_api: 2`） | `obs [1, 61]`, `h_in`, `c_in` | `actions [1, 14]`, `h_out`, `c_out` |

所有张量 float32、按名字匹配（与顺序无关）。**LSTM 导出必须标 `model_api: 2`**，
老 daemon 会拒绝安装；前馈是 API 1。

### 2.3 CPU 彩排：上真机前的最后一次检查

彩排解决两个不同的问题，用的是两个不同的工具（**以下命令是 linux 环境**）：

| 彩排 | 在哪跑 | 回答什么问题 | 工具 |
| --- | --- | --- | --- |
| ① 训练仓彩排 | 开发机 MuJoCo 仿真 | 策略动作合不合理？能不能走/站/起身？ | `infer_policy.py`  |
| ② 上板仓彩排 | **板子上**、生产 Rust 推理路径 | 板子跑不跑得动？延迟够不够 50 Hz？ | `policy-rehearsal` |

**两者都要做，顺序不能换**：先在训练仓看动作（行为对不对），再去上板仓测延迟（性能够不够）。
下面分开讲。大部分人会栽在②的一个认知上，先看②。

#### 2.3.1 训练仓彩排：看动作对不对（仿真）

在训练仓 `microduck_rl` 里，用 MuJoCo + 真实执行器参数（默认已是 hd1910 电机模型）把策略跑一遍：

```bash
# 训练仓（microduck_rl）目录下
uv run scripts/infer_policy.py --walking walk_hd1910.onnx --motor hd1910
```

它会弹出一个 3D 查看器，你就能用方向键驱动它，直观确认策略行为正常。
这一步**只验证动作合理性，测不了延迟**——仿真机比板子快，仿真时间不代表板上时间。

> 💡 前一步 §2.2 的"3D 演示"也是类似的目的（`uv run play ...`），但它加载的是 checkpoint，
> 而这里加载的是**导出后的 ONNX**——观测归一化已经烘焙进去，行为应当一致。以 ONNX 的结果为准。

#### 2.3.2 上板仓彩排：测延迟（板子跑不跑得动）

**⚠️ 摆正认知：这条彩排必须在板子上跑，不是在开发机上。**
官方文档（`docs/recurrent-policies.md` §Offline rehearsal）写得很明确：
"Run the built example **on the Radxa** to establish onboard timing;
development-host timings do not establish the robot's timing budget."
开发机的 CPU 比板子快得多，你拿开发机的 p50 去判断"能不能跑 50Hz"，
等于拿 i9 的帧率给手机做性能预算。**板子的耗时才是真预算。**

彩排目标：确认策略在 **50 Hz 控制环**（每步预算 20 ms）下，推理延迟不超标。
注意这个时间**只算 actor 推理**，不含传感器读取、电机写入和调度开销。

完整步骤如下：

**第 1 步：确认模型是官方导出器导出的**（§2.2 已做）

`uv run scripts/export.py` 把观测归一化**烘焙进 ONNX**，并写入 `model_api`/`obs_len`/
`action_len` 等 metadata。手工转换丢归一化，仿真里看不出问题，上了真机才露馅。
上板前先看一眼维数契约（在开发机的 Python REPL 或 venv 里跑）：

```python
import onnx
m = onnx.load("standup_hd1910.onnx")
print([(i.name, [d.dim_value for d in i.type.tensor_type.shape.dim]) for i in m.graph.input])
# 期望: [('obs', [1, 61])]
print([(o.name, [d.dim_value for d in o.type.tensor_type.shape.dim]) for o in m.graph.output])
# 期望: [('actions', [1, 14])]
```

前馈模型是 `obs[1,61] → actions[1,14]`；LSTM 还要多出 `h_in/c_in → h_out/c_out`，
且 metadata 必须标 `model_api: 2`，否则老 daemon 会拒绝安装（§2.2 产出契约）。

**第 2 步：把模型拷到板子**

这一步用 `scp` 传文件是**正常的**——它只是把待测模型送进板子，**不等于上板部署**。
真正上板要等彩排通过之后，走 §2.4/§2.5 的发布 + `robotctl policy` 通道。

```bash
# 在开发机（Windows PowerShell）上执行
scp e:\optiDuck\microduck_rl\standup_hd1910.onnx radxa@192.168.31.30:/home/radxa/

# 传完先核对 MD5，防止传输损坏（坏模型会给出完全不同的彩排结果）
# 开发机: Get-FileHash standup_hd1910.onnx -Algorithm MD5
# 板子上: md5sum /home/radxa/standup_hd1910.onnx
```

**第 3 步：确认板子彩排前置条件（Rust + ONNX Runtime）**

彩排要在板子上**现场编译** `duck-control`，需要两样东西，缺哪个装哪个：

```bash
# ① Rust 工具链在不在
cargo --version

# ② ONNX Runtime 动态库在不在（duck-control 通过 dlopen 加载它，不打包）
#    §7 的 setup-board.sh 装的是 1.28.0
find / -name "libonnxruntime*" 2>/dev/null
```

- **缺 Rust**（`command not found`）→ 往下看"装 Rust"小节
- **缺 ORT**（find 无输出）→ 跑 `setup-board.sh`（或单独装 ORT 1.28.0）

**→ 装 Rust（板子上没有 cargo 时执行）**

用 rustup 装到用户目录，**不需要 sudo**：

```bash
# ① 国内网络先配镜像，再装（官方源在国外，直连大概率超时；换源能省非常多时间）
export RUSTUP_DIST_SERVER=https://rsproxy.cn
export RUSTUP_UPDATE_ROOT=https://rsproxy.cn/rustup

# ② 安装（--profile minimal 只装 rustc/cargo，够编译用）
curl --proto '=https' --tlsv1.2 -sSf https://sh.rustup.rs | sh -s -- -y --profile minimal

# ③ 让当前终端生效（rustup 装完不会自动加载环境变量）
source "$HOME/.cargo/env"

# ④ 验证
cargo --version
rustc --version
```

> 💡 **镜像没配就装**：rustup 默认从 `static.rust-lang.org` 拉工具链，在板子上（尤其国内网络）经常卡死或超时。
> 上面的 `rsproxy.cn` 是字节跳动的 Rust 镜像，配完基本秒下。如果装完 cargo 还是慢（拉 crates 依赖时），
> 再配 crates 镜像：`~/.cargo/config.toml` 里写 `[source.crates-io] replace-with = 'rsproxy'` + 对应 registry 地址（教程 §10 有完整配置示例）。

彩排**不碰电机总线**，所以不需要电机上电、不需要接舵机——板子空转也能测。

**第 4 步：把上板仓代码弄到板子**

彩排的 `cargo run` 必须在上板仓目录内执行（那里才有 `Cargo.toml`），而板子上默认**没有**上板仓代码——
新手最容易在这里卡住：在 `~` 下跑 `cargo run` 报 `error: could not find Cargo.toml in /home/radxa`。
所以先把上板仓源码弄到板子上：

```bash
# ① 在板子上，下载并解压上板仓（用 codeload 下载 tar.gz）
#    GitHub 直连（github.com）在板子上经常超时，codeload 是官方内容分发域名，稳得多
cd /home/radxa
curl -L -o microduck.tar.gz https://codeload.github.com/pollen-robotics/microduck/tar.gz/refs/heads/main
tar -xzf microduck.tar.gz
ls   # 应看到 microduck-main 目录

# ② 先配 crates 镜像再编译（板子上拉 crates 依赖，不配镜像会非常慢甚至失败）
mkdir -p ~/.cargo
cat > ~/.cargo/config.toml <<'EOF'
[source.crates-io]
replace-with = "rsproxy"

[source.rsproxy]
registry = "sparse+https://rsproxy.cn/index/"

[registries.rsproxy]
index = "sparse+https://rsproxy.cn/index/"

[net]
git-fetch-with-cli = true
EOF
```

> ⚠️ **复制粘贴反引号陷阱（真实踩坑）**：本文档的 URL 在界面里渲染成代码样式（两边带反引号 `` ` ``）。
> 从对话/文档**复制 heredoc 时，这些反引号会被一起复制进文件**，导致 cargo 解析 URL 失败。
> 症状：`cat ~/.cargo/config.toml` 看到 `registry = "sparse+`https://...`"` 两边带反引号。
> 修复：`sed -i 's/`//g' ~/.cargo/config.toml`（或干脆用下面的 scp 方案重写）。
> **最稳妥的做法**：不在板子上粘贴含 URL 的命令，而是从开发机生成配置文件再 scp 上去：

```powershell
# 在开发机（Windows PowerShell）生成干净配置，scp 到板子覆盖
# （本地建一个 cargo-config.toml，内容就是上面 heredoc 里的 6 行，确保 URL 无反引号）
scp cargo-config.toml radxa@192.168.31.30:/home/radxa/.cargo/config.toml
# 上板后验证：cat ~/.cargo/config.toml 应看到 registry = "sparse+https://rsproxy.cn/index/" 无反引号
```

> `sparse+` 是 rsproxy 官方推荐的增量 index 格式，比整包 git 拉 index 快很多，板子必用。

> 💡 **为什么用官方 `pollen-robotics/microduck`**：板子的更新器（`updater.toml`）配的就是这个仓库、
> 板上 daemon 也是它的代码。彩排的意义就是测**和板上相同代码**的推理路径，所以必须用同一个仓库。
> 注意：本机 `e:\optiDuck\joyandai\microduck` 这个目录**也只是官方仓库的一份 clone**（remote 指向
> `pollen-robotics/microduck`，本地无私有提交）——GitHub 上并不存在独立的"JoyandAI 版上板仓"。
> 国产化（HD1910 电机参数等）都在训练仓 `microduck_rl`、已烤进 ONNX，上板仓保持纯官方即可。

**第 5 步：在板子上编译并运行彩排**

```bash
# 在板子上、上板仓目录内执行（第 4 步解压出的 microduck-main）
cd /home/radxa/microduck-main
export ORT_DYLIB_PATH=/usr/local/lib/libonnxruntime.so   # 第 3 步 find 到的实际路径
cargo run --release -p duck-control --example policy-rehearsal -- \
  /home/radxa/standup_hd1910.onnx > rehearsal.json

# 查看结果
cat rehearsal.json
```

首次编译要拉依赖 + 编译 release，会花几分钟；之后的 `cargo run` 增量编译就快很多。
**板子上网不便时**：可以在开发机用 `cargo build --release` 交叉编译出二进制拷过去，
但 ORT 动态库必须是板子上的（架构一致），且**时间必须在板子上实测**——交叉编译只是省编译时间，不能省实测。

**第 6 步：解读结果，判断能否上板**

```json
{
  "steps": 1000,
  "latency_ms": {"p50": 2.1, "p95": 3.4, "p99": 5.2, "max": 9.8},
  "over_20_ms": 0,
  "actions": [[...], [...], ...]
}
```

判定标准：

| 指标 | 要求 | 说明 |
| --- | --- | --- |
| `p95`/`p99` | 明显低于 20 ms | 50 Hz 控制环每步预算 20 ms，尾部延迟太高会周期超时 |
| `over_20_ms`  | 最好是 0 | 超过 20 ms 的次数；非 0 意味着有控制步会被拖过预算 |
| `max` | 越低越好（首推可能偏高属正常，预热已做） | 峰值延迟，决定最坏情况 |
| `actions` | 与前馈推理逐项对比（可选） | 用带 obs 的 trace 对比 PyTorch/Python ORT，校验推理一致性 |

只有板子上测出的 `p95/p99/max` 都稳在 20 ms 内、`over_20_ms` 为 0，策略才算通过彩排，
可以进入 §2.4 发布。**不要**用开发机的测量结果替代——那只能证明模型结构没问题，
证明不了板子跑得动。

> ⚠️ **彩排 ≠ 上板**：彩排只是"用生产推理路径测延迟"，它**不写任何板子配置、
> 不占策略槽位、不需要电机**。真正把策略装进板子（`robotctl policy add`/`load`）是
> 彩排通过之后、发布完成之后的事（§2.5）。别把这两步搞混——彩排阶段就把模型
> `robotctl policy load` 进槽位，属于跳过流程的误操作。

### 2.4 发布到 HF Hub：一个模型变成一个"仓库"

> 📌 **先分流：发布不是必经之路**。如果模型只在自己的板子上用，可以跳过本节，
> 直接走 §2.5 的 `sudo robotctl policy load <槽位> /home/radxa/xxx.onnx`（本地文件占槽，
> 持久生效）。走发布的意义：叫名字触发（`robot do`）、绑手柄按钮、分享给别人、
> 有 manifest 校验和版本管理。两条路见 §2.5 末尾的对比。

**发布前置：HF 登录（一次性的）。** `uv run publish` 走 `huggingface_hub` 上传，
token 从两个地方找，**没有就不让你发**（报 `no cached HF token. Run hf auth login.`）：

> ⚠️ **本节的登录、发布命令都在开发机上执行**（发布模型的是开发机）。板子**不需要**
> HF token——它只通过 `robotctl policy add` 拉取**公开**策略仓，匿名即可；
> 在板子上跑 `hf auth login` 会报 `hf: command not found`（板子没装这套工具，也不需要）。

**先创建 token（第一次用 HF 时，网页操作，只需一次）：**

1. 打开 [https://huggingface.co/settings/tokens](https://huggingface.co/settings/tokens)（需已注册/登录 HF 账号），
   点 **Create new Access Token**
2. **Token type**：保持默认的 **Fine-grained**（不用动；创建后不可改）
3. **Token name**：随便起个名字（如 `microduck-publish`），方便以后辨认
4. **Presets**（预设按钮）：点 **⬆ Write** —— 这正是发布需要的权限集（对你名下仓库的
   读+写，覆盖 `create_repo` + `upload_folder`）。**不要选 Read-Only**（上传 401/403），
   也不必选 Full Access（权限过大没必要）；Custom 手动勾细项是给特殊场景的，发布用不上
5. 点 **Create token**，弹出 `hf_xxxxx` 后**立刻复制**——**只显示这一次**，关掉就再也
   看不到了，丢了只能重新创建

**方式 A（推荐）：huggingface_hub CLI 登录，token 缓存到本机**

`hf` 不是系统全局命令，它装在训练仓的 venv 里——**必须通过 `uv run` 调用**（在训练仓
`microduck_rl` 目录下执行；直接敲 `hf auth login` 会报 command not found）：

```powershell
# 开发机（Windows PowerShell），先 cd 到训练仓目录
cd E:\optiDuck\microduck_rl
uv run hf auth login
# 按提示：粘贴 hf_xxx token → 回车；"Add token as git credential?" 选 n 也行
```

**方式 B：临时用环境变量（不写盘，仅当前终端生效）**

```powershell
$env:HF_TOKEN = "hf_xxx"     # PowerShell；Linux 用 export HF_TOKEN=hf_xxx
```

**怎么确认 token 已经就位（发布前先验证，避免白跑）：**

```powershell
# 同样在 microduck_rl 目录下
uv run python -c "from huggingface_hub import whoami; print(whoami()['name'])"
# 打印出你的 HF 用户名 = 登录成功；报错 = token 没配上
```

**token 权限要求**：`publish` 要在你名下发仓库（`create_repo`）并上传文件
（`upload_folder`），必须用 **Write 权限**的 token（创建页 Presets 点 **⬆ Write** 即可；
只读 token 上传会 401/403）。`--repo <user>/microduck-<name>` 里的 `<user>` 就是
登录账号的 HF 用户名，publish 会**自动从 token 推断**——所以先登录、用户名填自己的。

> 💡 如果你之后用 `uv run train ... --hf-jobs` 在 HF 上跑训练，那是另一个
> **带 Jobs 权限**的 fine-grained token，与本地发布不是一回事（`hf_jobs.py` 里
> token 鉴权通过但缺 Jobs 权限会明确报 "token-scope problem, not billing"）。

**manifest.json 是什么、为什么需要它**：板子**不认裸的 `.onnx`**。安装策略时，
`robotctl policy add` 会检查模型旁边一个 `manifest.json`——模型的"身份证"，写明：
给谁用的（`robot.model: microduck`，写错直接拒装）、输入输出维度（`obs_len: 61` /
`action_len: 14`，和板子对不上就拒装）、什么类型（episodic/perpetual）、跑几秒、
训练来源（便于溯源）。所以"发布" = **policy.onnx + manifest.json + README 三个文件
一起**上 HF Hub，板子拉取后验 manifest 通过才装。

**你不需要手写 manifest**——训练仓的 `publish` 命令根据参数**自动生成**它，并做
上传前体检（61→14 维度校验 + NaN 冒烟测试），不合格不会传（`microduck_rl/AGENTS.md`）。
权重来源有两种（**下述两种来源只是作为解释，已在2.2导出ONNX执行过**）：

```bash
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

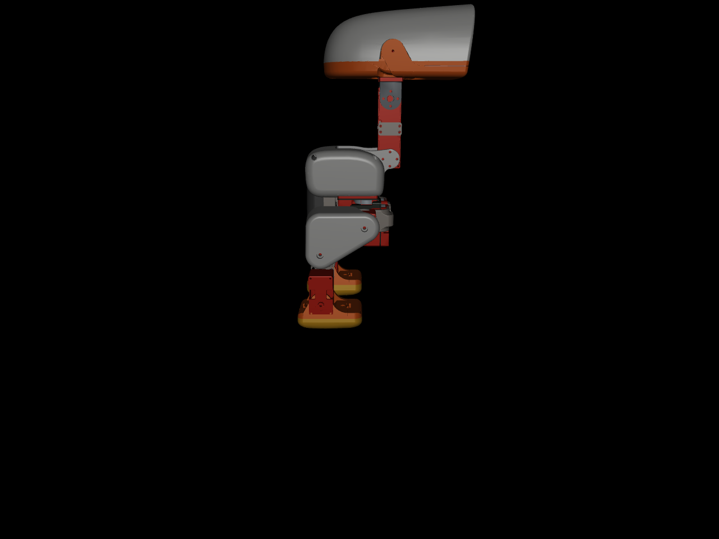
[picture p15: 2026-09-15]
assets/renders/model_openmicroduck_front.png

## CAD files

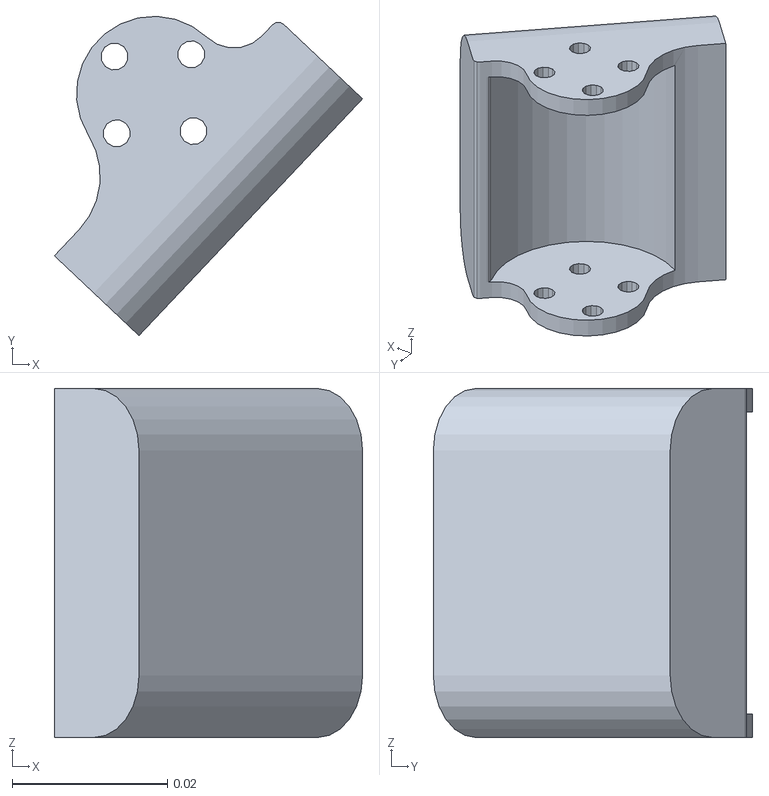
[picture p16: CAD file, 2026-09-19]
tools/urdf/mjcf-preview/models/open_duck_assets/ankle_left.STL
0.0397 x 0.0412 x 0.045

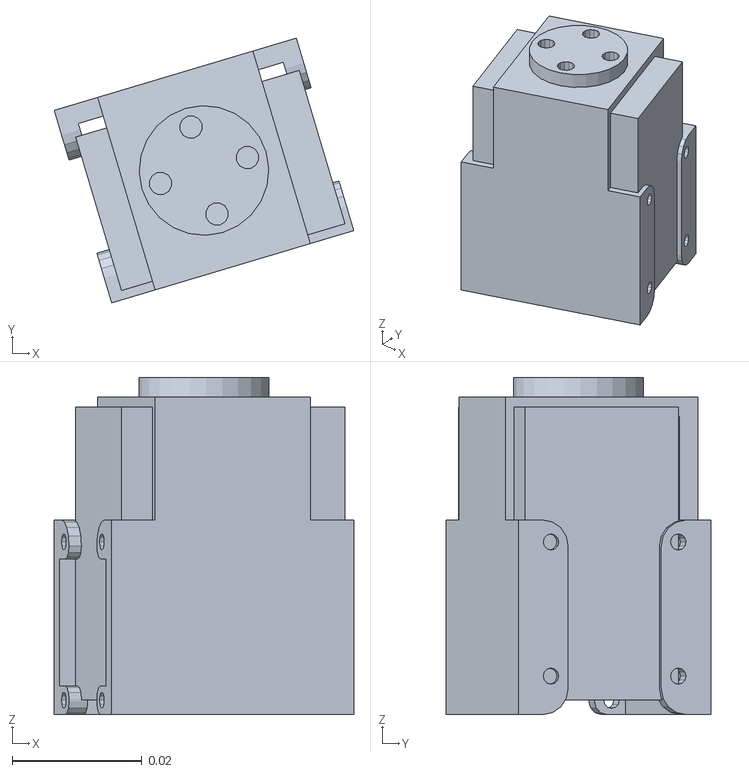
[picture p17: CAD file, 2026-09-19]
tools/urdf/models/open_duck_urdf/open_duck/meshes/yaw2roll.STL
0.0462 x 0.0409 x 0.052

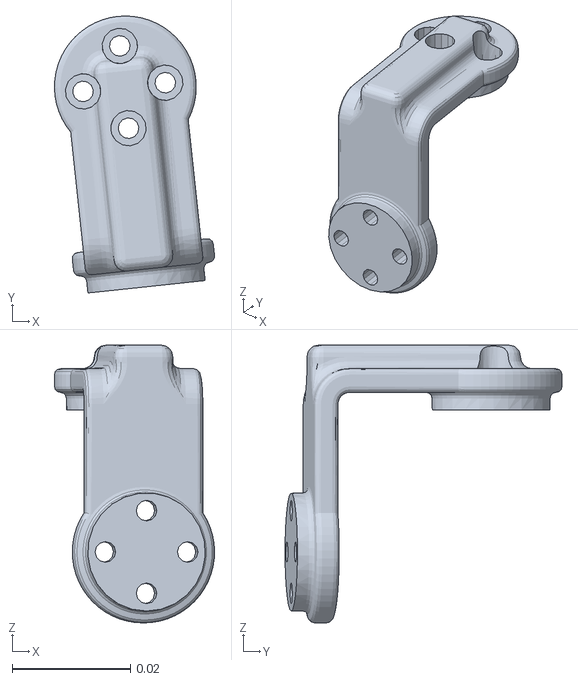
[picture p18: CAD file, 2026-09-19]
training/microduck_rl/src/mjlab_microduck/robot/crazy_chick/open_duck_assets/hip_l_2.STL
0.0271 x 0.0469 x 0.047

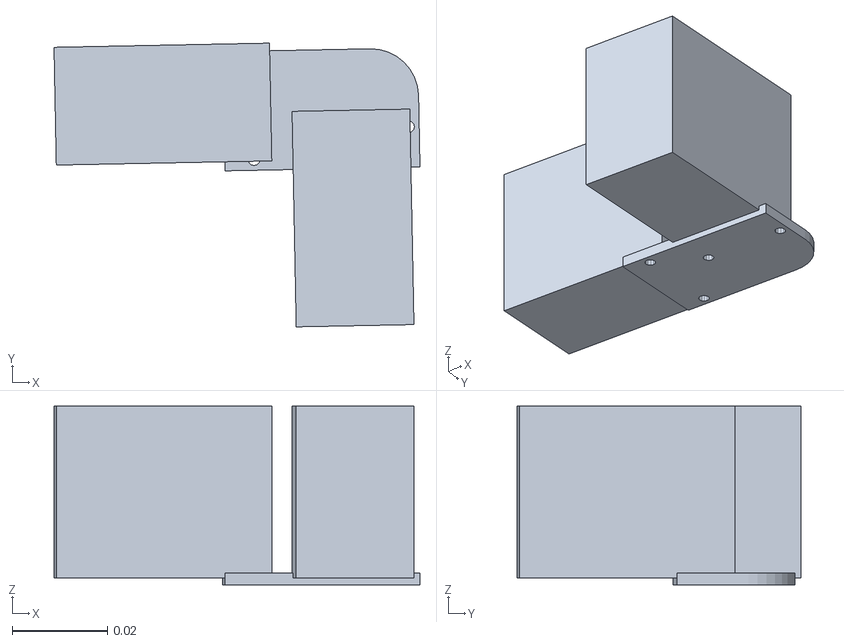
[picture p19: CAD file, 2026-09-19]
tools/urdf/mjcf-preview/models/open_duck_assets/upper_leg_right.STL
0.0767 x 0.0595 x 0.0375

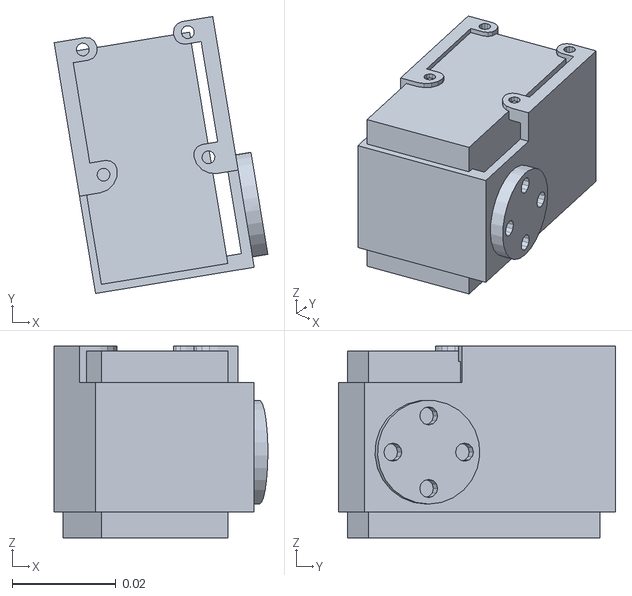
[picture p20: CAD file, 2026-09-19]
tools/urdf/models/open_duck_urdf/open_duck/meshes/yaw_roll_motion.STL
0.0412 x 0.0534 x 0.037

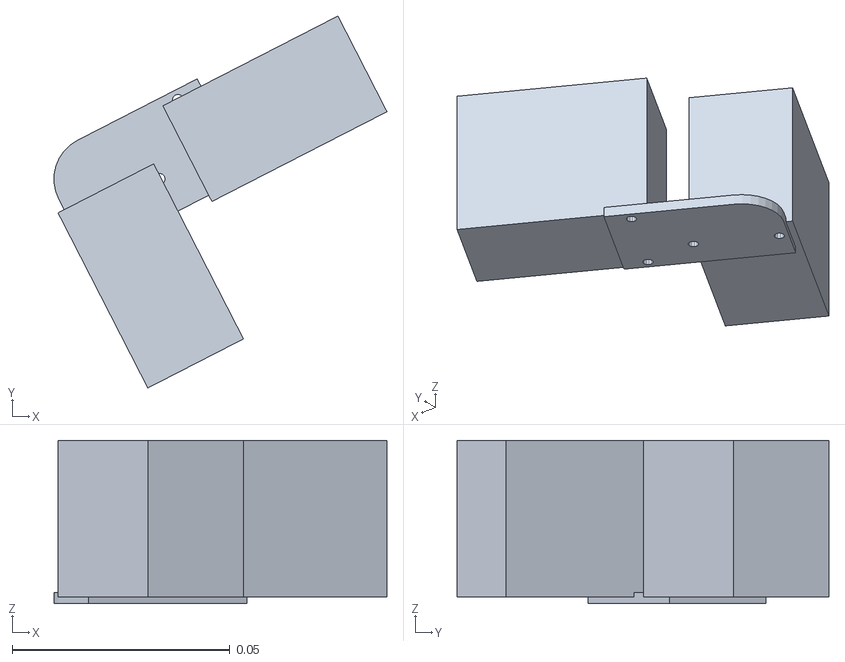
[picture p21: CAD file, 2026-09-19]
tools/urdf/models/open_duck_urdf/open_duck/meshes/upper_leg_left.STL
0.0765 x 0.0854 x 0.0375

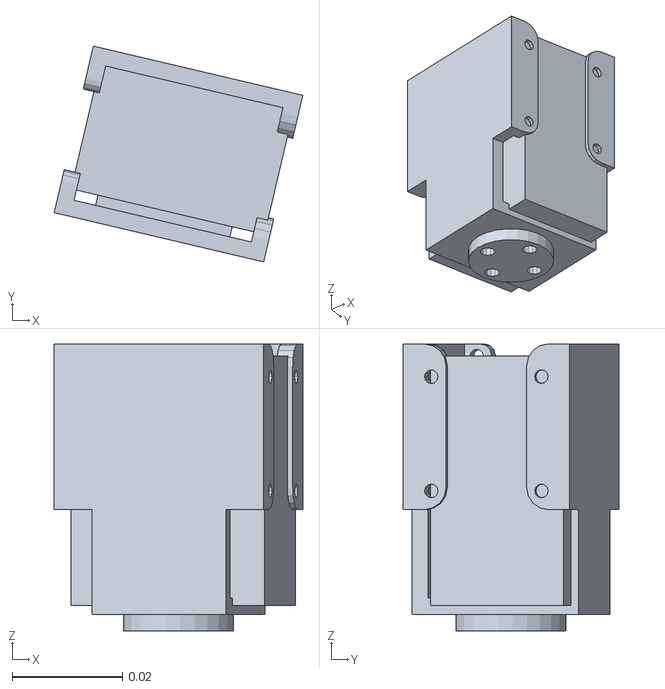
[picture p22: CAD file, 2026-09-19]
training/microduck_rl/src/mjlab_microduck/robot/crazy_chick/open_duck_assets/bearing_roll.STL
0.0451 x 0.0391 x 0.052

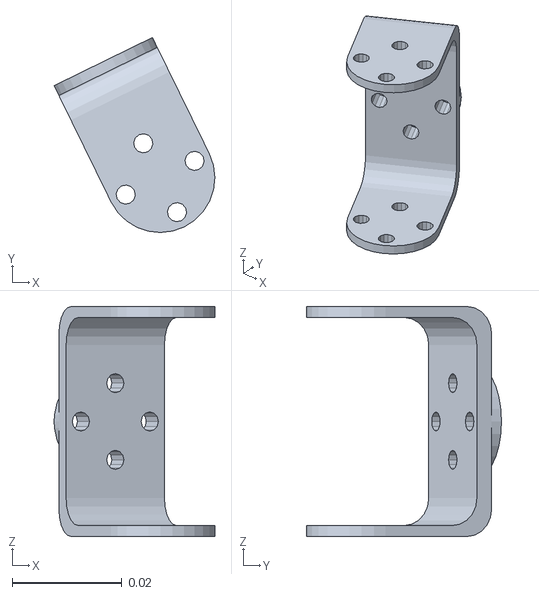
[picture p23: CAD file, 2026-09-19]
training/microduck_rl/src/mjlab_microduck/robot/crazy_chick/open_duck_assets/neck_pitch.STL
0.0294 x 0.0356 x 0.042

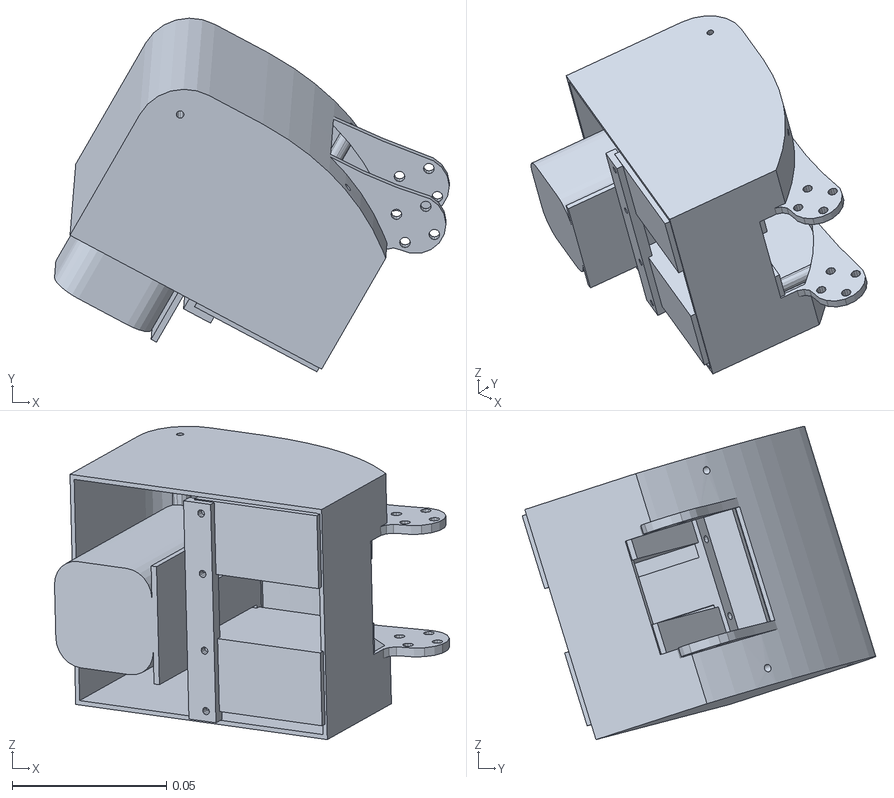
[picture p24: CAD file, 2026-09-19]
tools/urdf/models/open_duck_urdf/open_duck/meshes/base_link.STL
0.128 x 0.115 x 0.101

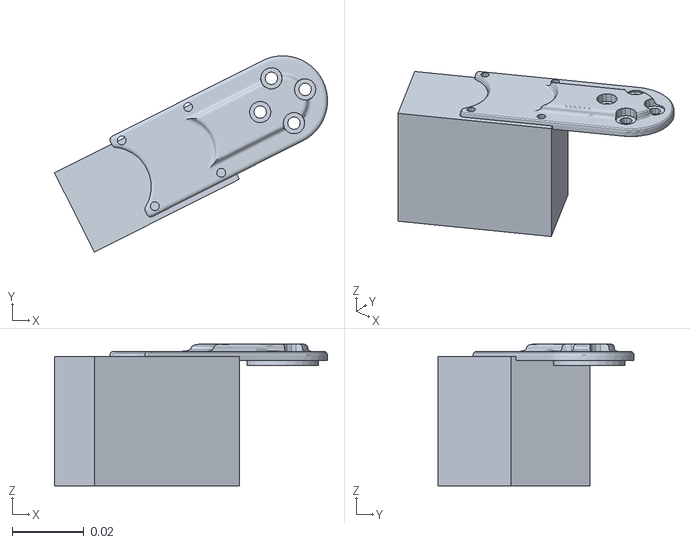
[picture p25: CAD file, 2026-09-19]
training/microduck_rl/src/mjlab_microduck/robot/crazy_chick/open_duck_assets/leg_2.STL
0.076 x 0.0546 x 0.0394

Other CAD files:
_scratch_archive/cad/_hd1910_tmp.stl
_scratch_archive/cad/_xl330.stp
tools/urdf/mjcf-preview/models/open_duck_assets/ankle_right.STL
tools/urdf/mjcf-preview/models/open_duck_assets/hip_l.STL
tools/urdf/mjcf-preview/models/open_duck_assets/jaw_soft.STL
tools/urdf/mjcf-preview/models/open_duck_assets/leg.STL
tools/urdf/mjcf-preview/models/open_duck_assets/neck.STL
tools/urdf/models/open_duck_urdf/open_duck/meshes/ankle_right.STL
tools/urdf/models/open_duck_urdf/open_duck/meshes/hip_l.STL
tools/urdf/models/open_duck_urdf/open_duck/meshes/jaw_soft.STL
tools/urdf/models/open_duck_urdf/open_duck/meshes/leg.STL
tools/urdf/models/open_duck_urdf/open_duck/meshes/neck.STL
training/microduck_rl/src/mjlab_microduck/robot/crazy_chick/open_duck_assets/ankle_right.STL
training/microduck_rl/src/mjlab_microduck/robot/crazy_chick/open_duck_assets/hip_l.STL
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

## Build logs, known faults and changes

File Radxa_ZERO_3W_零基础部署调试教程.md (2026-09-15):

# Radxa ZERO 3W 零基础部署与调试教程

> **本教程已踩过坑、验证过可行**（2026-09-15 实战更新），针对你的实际硬件：
> **Radxa ZERO 3W / RK3566 / 2GB LPDDR4 / 无 eMMC**，开发主机为 **Windows + PowerShell**。
> 目标：把一块"刚拆封、什么都不会"的空白板子，变成可以登录、可以跑机器人控制软件、知道怎么排障的开发板。
>
> 内容依据 `E:\optiDuck\joyandai\microduck` 的官方文档（`docs/onboarding.md`、`docs/robot/install-dev.md`、`docs/robot/cheatsheet.md`、`docs/robot/install-by-hand.md`、`deploy/README.md`）+ `E:\optiDuck\OpenMicroDuck\docs` 硬件文档 + 2026-09-15 实战踩坑经验。

## 怎么读这份教程

每一步都按同一套四问写清楚，你可以只看你需要的那一问：

| 标记 | 含义 |
| --- | --- |
| **在干吗** | 这条命令 / 这个动作，在系统里到底发生了什么（不是"照着敲"，而是知道它在动什么） |
| **为什么必须做** | 不做会怎样；以及为什么是这个做法而不是别的做法 |
| **完成标志** | 怎么算成功 —— 用可观察的输出判断，不靠"感觉应该行" |
| **卡住了怎么办** | 这一步最常见的失败长相 + 往哪查 |

同时标注每个步骤的性质：

- **【动手】** = 会改变板子/卡的状态，敲下去就有后果；
- **【只读】** = 纯查看，不改任何东西，放心跑；
- **⚠️** = 已知会失败、或者是坑的地方（在你这块 Radxa OS 上尤其要注意）。

> 通读建议：第一次做，**按 §2 → §13 的顺序**；出问题直接跳 §0（踩坑史）和 §11（速查表）；想搞懂"为什么每一步长这样"，看 §6.6 / §6.7（现象 → 原理）和 **§10（拆箱总纲：剩下所有黑箱 + 通用拆解方法）**。

---

## 🚨 0. 先看：踩坑血泪史（必看！帮你节省 2~3 小时）

> **这是你之前 initramfs 卡了整整一个下午的真实原因**，按影响程度排序：

### 0.1 电源不够 → 板内核能起来、但 **TF 卡物理设备都识别不到**

- **症状**：板子亮、HDMI 有输出、内核起来了，但 initramfs 里 `ls /dev/mmcblk*` 报 `No such file or directory`；
- **根因**：你旧手机的 5V/1A 充电头 + 细 Type-C 线，电流不够，RK3566 的 SDIO 控制器起不来；
- **修法**：换一个 **5V/2A 或 3A** 的充电头 + **粗一点的 Type-C 线**（比如小米 90W PD 快充头 + 5A 粗线，亲测解决）。**电压必须是 5V（Type-C 默认），不会烧板子，放心用大电流**。
- **验证**：换电源后重上电，`blkid` 应该能看到 `/dev/mmcblk1`（Radxa ZERO 3W 无 eMMC，SD 卡走 mmcblk1；有 eMMC 的板子 SD 卡走 mmcblk0）。

### 0.2 Windows 上烧 Armbian 镜像的已知 bug → 分区表被清掉

- **症状**：Armbian imager 校验显示"写入成功"，但板子启动后 initramfs 里 `blkid` 只看到 `/dev/mmcblk1: PTUUID=... PTTYPE="gpt"`（**空 GPT 分区表**——只有一张分区"目录"，实际 p1/p2 分区内容全丢了）；
- **根因**：Windows 上的 Armbian imager / Etcher / Rufus 在写入后会被 Windows 的 **分区管理安全机制** 干扰——Windows 看到一个带 GPT 头但没有有效分区的磁盘时，可能自动重新生成一张空 GPT，把镜像实际写入的分区内容覆盖掉；
- **修法**（三选一，按推荐顺序）：
  1. **换 Radxa OS 官方镜像 + balenaEtcher 烧录**（本教程推荐，已验证成功，见 §3）；
  2. 实在要用 Armbian → 用 **Win32 Disk Imager** 或 **WSL 里的 `dd`**（直接操作块设备扇区，绕过 Windows 分区管理）；
  3. 烧完后**立刻弹出 TF 卡，绝对不要在 Windows 上点任何"格式化"、"修复驱动器"、"扫描"弹窗**。

### 0.3 Armbian 的设备树里只有通用 `radxa-zero3`，没有 ZERO 3W 专用 dtb

- **症状**：板子能启动但 Wi-Fi 不工作 / eMMC 不识别 / 某些 GPIO 控制器找不到；
- **根因**：Armbian 26.8.1 的 vendor 内核（6.1.115）**只 ship 了 `rk3566-radxa-zero3.dtb`，没有 3W 专用的 `rk3566-radxa-zero-3w.dtb`**——3W 有 Wi-Fi/BT 模块（aic8800），占用 SDMMC1 控制器，设备树必须包含对应的 pinctrl/regulator 配置；
- **修法**：直接用 **Radxa OS 官方镜像**（它自己维护设备树，自动识别 ZERO 3W / 3E），绕开这个问题。

### 0.4 Windows PowerShell 的 `$env:USERPROFILE` 展开坑

- **症状**：教程里写的
  ```
  type $env:USERPROFILE\.ssh\id_ed25519.pub | ssh user@ip "cat >> ~/.ssh/authorized_keys"
  ```

  报 `Get-Content : 无法将参数绑定到"Path"，因为该参数是空值`；
- **根因**：PowerShell 管道 + 环境变量展开 + 中文路径（你的用户名是"刘"）这三个因素的组合 bug；
- **修法**：**不用管道**，改用 `scp` 直接把公钥文件拷到板子，再在板子上手动合并（见 §5.2）。

### 0.5 SSH 连不上 Connection refused → 板子上没装 openssh-server

- **症状**：板子能 ping 通、IP 正确、但 `ssh` 报 `Connection refused`；
- **根因**：Radxa OS 出厂**没装 openssh-server**（或装了但没启动）；
- **修法**：在板子的本地终端（HDMI+键盘）跑 `sudo apt install -y openssh-server && sudo systemctl enable --now ssh`。

### 0.6 initramfs 里 `ls /dev/mmcblk*` 两种情况的硬核区别

| 情况 | `ls /dev/mmcblk*` 输出 | 根因 |
| --- | --- | --- |
| ❌ 卡完全没读到 | `No such file or directory` | 电源不够！换 90W 头 / 粗线 |
| ⚠️ 卡读到但空分区 | `/dev/mmcblk1` 存在，但 `blkid` 只有 `PTUUID=... PTTYPE=gpt`（没 p1/p2） | 烧录被 Windows 干扰了，换 Radxa OS + Etcher 重烧 |
| ✅ 正常 | `/dev/mmcblk1p1` + `/dev/mmcblk1p2` 都有，`blkid` 输出带 `UUID=` 和 `TYPE=` | 烧录正确，UUID 对得上 cmdline.txt 就能启动 |

### 0.7 重启后 Wi-Fi 不自动连 → 开机 SSH 失联（密码被存进"用户密钥环"）

- **症状**：在桌面/终端里手动连上 Wi-Fi 后一切正常，但**重启后板子不联网、SSH 连不上**；接上显示器，只要**选账户输一次密码登录**，Wi-Fi 立刻自己就通了 —— 看着像"必须先登录才行"，其实是**密码取不到**；
- **根因**：这个 Wi-Fi 连接的密码（PSK）是**以用户身份**保存的：Keyfile 里写着 `psk-flags=1`（agent-owned），**文件里根本没有 `psk=` 这一行**。NetworkManager 开机时以 root 身份运行，取密码要靠桌面会话里的 `secret agent`；而你屏蔽 sddm（图形登录）之后，开机**没有任何用户会话 → 没有 agent → 直接判失败**：
  ```
  (wifi) access point '天问412' has security, but secrets are required.
  no secrets: No agents were available for this request.
  state change: need-auth -> failed (reason 'no-secrets')
  Activation: failed for connection '天问412'
  ```
- **一眼确诊**（在还能连上的时候跑）：
  ```bash
  sudo grep -n -E "psk-flags|^psk=" /etc/NetworkManager/system-connections/*.nmconnection
  ```
  看到 `psk-flags=1` 且**没有** `psk=` → 就是这个坑；
- **修法**（一条命令，把密码改成"系统所有"，开机不需要任何会话）：
  ```bash
  # 自动取 UUID，避免手输中文 SSID 踩 IME 坑
  UUID=$(nmcli -t -f UUID,TYPE connection show | awk -F: '$2=="802-11-wireless"{print $1; exit}')
  echo "$UUID"

  sudo nmcli connection modify "$UUID" wifi-sec.psk "<你的WiFi密码>" wifi-sec.psk-flags 0
  # 顺手把持久化属性一次配齐
  sudo nmcli connection modify "$UUID" \
    connection.autoconnect yes \
    connection.autoconnect-priority 100 \
    connection.autoconnect-retries -1 \
    802-11-wireless.powersave 2

  sudo reboot
  ```
  **验收**：重启后**不接显示器、不做任何登录**，等 90 秒直接
  ```powershell
  ssh radxa@<板子IP>
  ```
  能直接进 = 修好了（显示器上仍旧停在 `login:` 属于正常，与联网无关）；
- **两个小坑**：
  1. `nmcli connection modify` 设置时可以用别名 `wifi-sec.psk-flags`，但 `nmcli -f` **查询字段必须写全名** `802-11-wireless-security.psk-flags`，否则报 `invalid field`；
  2. 改完密码会**明文**存在 `/etc/NetworkManager/system-connections/*.nmconnection`（权限 `600`，仅 root 可读）——这是 NetworkManager 的标准做法，不是配置错误；
- **不需要排查的方向**（别浪费时间）：`wpa_supplicant` 是 active **属于正常**（Debian 上 NetworkManager 通过 D-Bus 调它做 WPA 握手），不是"抢占网卡"；`systemd-networkd` 应该 inactive。

---

## 1. 先搞清楚：这块板子在你项目里是干什么的

> **型号先确认清楚（别再纠结了）**：Radxa 官方**没有**一块叫 "ZERO 3" 的板子 —— **"ZERO 3" 只是这一代的系列名 / 文档目录名**，实际在售的只有两个型号：
>
> | | Radxa **ZERO 3W** | Radxa **ZERO 3E** |
> | --- | --- | --- |
> | 无线 | ✅ Wi-Fi 6 + BT 5.4（AIC8800D80） | ❌ 没有 |
> | 有线 | ❌ 没有网口 | ✅ 千兆以太网（支持 PoE，需另配 HAT） |
> | 存储 | 板载 eMMC **0**/8/16/32/64GB 可选 + microSD | 只有 microSD |
> | SoC / 内存 / 尺寸 | RK3566 / LPDDR4 1~8GB / 65×30mm | 与 3W 相同 |
>
> **你的板子 = ZERO 3W（eMMC 0GB 的 SKU）**：Wi-Fi 能连 + 没有 eMMC + 没有网口，三条特征全中，只可能是 3W。所谓"无 eMMC"不是另一个型号，而是 3W 的存储选配（0GB）。
>
> 被绕晕的来源：镜像名 `radxa-zero3_bookworm_kde_b1`、主机名 `radxa-zero3`、文档目录 `/zero/zero3/` —— **两个型号共用这套命名**，到处写着 "zero3"，但它不代表型号。
>
> 想自己再确认一次 —— **注意 `/proc/device-tree/model` 在 3W 和 3E 上都只打印通用的 `Radxa ZERO 3`，不带 W/E 后缀**（2026-09-15 在真机上验证过），所以别靠它区分型号：
> ```bash
> ls /sys/class/net/                      # 有 wlan0 → 3W；有 eth0 → 3E（3E 无无线，3W 无网口）
> ls /dev/mmcblk*                         # 只有 mmcblk1 → 无 eMMC；另有 mmcblk0/mmcblk2 → 有 eMMC
> cat /proc/device-tree/model; echo       # 只会打印通用串 "Radxa ZERO 3"
> ```

Radxa ZERO 3W 是鸭子的**"大脑/主控"**。整台 Microduck（约 25 cm、800g 的双足小鸭）由它负责：

- 跑一个 **50 Hz 控制回路**，读 15 个舵机 + 机身 IMU，组 61 维观测，用 ONNX 神经网络（强化学习策略）推理，输出 14 个关节目标，驱动舵机走路/站立/踢球/翻滚/起身；
- 一组 Rust 守护进程：`robotd`（控制/电机）、`configd`（Wi-Fi/名字/PIN）、`updaterd`（签名更新/回滚）、`btd`（蓝牙门面）、`padd`（手柄）、`mediad`（相机/推流）、`tofd`（头部深度传感器）；
- 板载 Wi-Fi + 蓝牙：手机 App（BLE）、游戏手柄、远程 WebRTC 都走这里。

**关键概念（先记住这三个，后面都好懂）：**

1. **走路策略在 CPU 上跑 ONNX Runtime（ORT），不在 NPU 上。** NPU 是给"视觉/鸭子检测"预留的，且默认是关的。所以"2GB RAM、无 eMMC"对走路这一关没有任何影响——官方那档甚至只有 1GB RAM。
2. **只有 `robotd` 能碰电机。** 其它进程（手柄、手机、脚本）发的都是"意图"，由 `robotd` 内部的安全层决定是否执行。
3. **更新 = 整目录替换 + 验签 + 健康门 + 自动回滚。** 装坏了自己会滚回去，不是打补丁。

> 你这块 2GB 内存比官方 1GB 还多，只会更充裕。**无 eMMC 不是缺陷**：意味着你从 microSD 卡启动（对零基础反而更简单，不需要进入 USB 烧录的 maskrom 模式），只是存储介质换成卡。

---

## 2. 你需要准备的东西

| 物品 | 要求 / 建议 | 用途 |
| --- | --- | --- |
| **microSD 卡** | **≥16GB，建议 32GB**，**A1/U3 速度等级**（Class 10 起步），正规品牌（SanDisk/Samsung/Kingston） | 系统就装在这张卡里（无 eMMC，卡就是硬盘） |
| **读卡器** | USB 读卡器（如果电脑没 SD 槽） | 写镜像到卡 |
| **电源** | **5V / 2A 或更高** 的 USB-C 充电头 + **粗一点的 Type-C 线**（小米 90W PD 头 + 5A 粗线亲测可用）  | 供电。电流不够 TF 卡/外设起不来 |
| **Micro-HDMI 转 HDMI 线** | 1 条（强烈建议第一次用） | 第一次开机接显示器，直接看到它有没有起来  |
| **USB 键盘 / USB HUB** | 第一次接线用（可选，但出问题时救命） | 直接登录；没有就用 SSH |
| **Wi-Fi** | 能上网的 2.4G/5G 路由，且你**知道密码** | 3W 没有网口，联网只能走 Wi-Fi |
| **能登录路由器后台** | 知道管理员地址（常见`192.168.31.1` / `192.168.1.1`） | 查板子的局域网 IP |

**电源选择速记：电压必须 5V（Type-C 默认，不会烧），电流越大越好（5V/3A、5V/5A、90W PD 头都 OK）。90W PD 头不会烧板子——板子只会按需取电流，多余的电流"空转"。**

---

## 3. 认识板子（接口速览）

- 尺寸 **65 × 30 mm**，和树莓派 Zero 一个外形、同样的安装孔位；
- 两个 USB-C：
  - **USB 2.0 OTG / PWR**（用于 **供电**，一般插电源的那头，这个口电流能力更强）
  - **USB 3.0 Host**（可接键盘/鼠标/摄像头等外设，**别拿这个口供电**，电流能力弱）
- **Micro HDMI**（输出显示，最高 1080p60）
- **microSD 卡槽**（系统所在处，无 eMMC 的板子**只能从这里启动**）
- **22 针 CSI 排线座**（摄像头）
- **40 针 GPIO**（3.3V，连到 HAT/扩展板上，舵机总线、IMU、ToF、喇叭都走这里）

和机器人硬件相关的关键引脚（后面调试时会反复见到的设备名）：

| 功能 | 设备路径 | 说明 |
| --- | --- | --- |
| 舵机总线 | `/dev/ttyS2`（UART2） | 15 个舵机 + 机身 IMU 共用一条半双工 TTL 总线 |
| 机身 IMU | `/dev/i2c-imu`（i2c4，地址 `0x6A`） | LSM6DSV16X，独立总线（2026-09-04 起从舵机总线上拆出来了） |
| 音频 codec + 头部 ToF | `/dev/i2c-pihat`（i2c3） | TLV320AIC3104 codec（`0x18`）+ VL53L5/8CX 深度传感器（`0x29`） |
| 喇叭数据 | I²S3 | 声音不走策略网络 |
| 摄像头 | CSI | IMX219 一类模组 |

---

## 🎯 4. 烧录系统到 SD 卡（**按这个来，别换**）

> **踩坑结论**：Windows + Armbian imager / Etcher 烧 Armbian 镜像在 Zero 3W 上会出现"空 GPT 分区表"问题。**直接用 Radxa OS 官方镜像 + balenaEtcher**，已验证成功。

### 4.1 【动手】下载 Radxa OS 官方镜像

- **官方下载页**：`https://docs.radxa.com/zero/zero3/download`
- 找 **官方镜像** 区块，下载 **6.1 内核的那个**：`radxa-zero3_bookworm_kde_b1`
  - 文件是 `.img.xz` 压缩包（约几十到几百 MB）；
  - **不用解压**，Etcher 支持直接写 xz 压缩包；
  - 如果 GitHub 下载慢，Radxa 页底部有百度网盘镜像。

**在干吗**：在挑一块"装机盘"。你的板子**没有 eMMC**（没有板载硬盘），操作系统没有任何地方可去，只能整份装在 microSD 卡里 —— 所以这一步选的不是"一个软件"，而是这块板子的**整个硬盘内容**。

**为什么必须做 / 为什么只能是 Radxa OS**：两个理由，都在 §0 里踩过 —— ① Armbian 镜像在 Windows 上烧会出现"空 GPT 分区表"（§0.2）；② Armbian 的设备树里只有通用的 `rk3566-radxa-zero3.dtb`，没有 3W 的 Wi-Fi 配置（§0.3）。Radxa OS 是板厂自己维护的，设备树天然对得上你的板子，Wi-Fi、SD 卡、GPIO 开箱即用。

**为什么是 6.1 内核那个**：同页面还有 5.10 内核的旧版（`radxa-zero3_debian_bullseye_xfce_b6`）。选新不选旧 —— 后面的 ONNX Runtime、NetworkManager 版本都更配合新版 Debian。

**完成标志**：本地有一个 `.img.xz` 文件，大小对得上页面标注的数值。

**卡住了怎么办**：GitHub 直连慢/断 → 用页面底部的百度网盘镜像。下载完可以顺手核对页面给的 SHA256（不是必须）。

> 备注：Radxa OS 只有 KDE 桌面版（没有 Minimal/CLI 版）。2GB RAM 能跑，后面装完机器人驱动可以一键卸掉 KDE 省空间。

### 4.2 【动手】下载 balenaEtcher

- Windows 版下载：`https://github.com/balena-io/etcher/releases/download/v1.18.11/balenaEtcher-Setup-1.18.11.exe`
- 官方镜像页也推荐 Etcher（Radxa 自己都用它）。

**在干吗**：装一个"写盘工具"。它的作用等价于 Linux 的 `dd` —— 把镜像文件**逐扇区原样**写进 SD 卡，包括分区表、引导记录、文件系统。

**为什么必须做 / 为什么不能用资源管理器复制**：Windows 把 SD 卡当成"U 盘"，只能往里丢文件；而"可引导的系统盘"需要分区表和引导扇区，这是资源管理器和"格式化为 FAT32"都做不到的。你把 `.img.xz` 拷到卡里，板子是绝对启动不了的。

**完成标志**：`balenaEtcher` 能打开（安装时 Windows 可能弹 UAC，允许即可）。

### 4.3 【动手】烧录步骤（**按顺序，别漏**）

1. **TF 卡插进电脑读卡器** → 等 Windows 识别到盘符；
   - *在干吗*：让卡以"可移动磁盘"的身份出现在 Windows 里，Etcher 才看得见它。
   - *先记两个东西*：它的**盘符**（比如 `E:`）和**容量**（比如 29.7GB）。下一步要靠这两个认卡 —— 尤其容量。
2. **打开 Etcher** → 点 **「Flash from file」** → 选你刚才下的 `.img.xz` 镜像；
   - *在干吗*：告诉 Etcher"要写什么"。xz 是压缩包，**不用解压**，Etcher 边解压边写。
   - *为什么先选镜像再选盘*：Etcher 的默认流程是「选镜像 → 选目标 → 写入」；先选镜像，它才好过滤掉不合理的目标（比如系统盘）。
3. **点「Select target」** → **务必认准你的 TF 卡容量**（Windows 里会显示成 "29.7GB / 31.3GB" 之类的可移动磁盘，**绝对不要选电脑硬盘！**）；
   - *在干吗*：告诉 Etcher"往哪写"。
   - ⚠️ **这一步是整个教程里唯一会毁数据的操作**：选错盘 = 把你自己电脑的硬盘整个覆盖掉，且不可恢复。**认容量不认盘符**（盘符会变，容量不会）。拔掉其他 U 盘/移动硬盘再选，更保险。
4. **点「Flash!」** → 等进度条走完 → Etcher 会自动校验；
   - *在干吗*：写盘 + **读回来逐字节比对**（这就是 Etcher 比"复制粘贴"靠得住的地方）。
   - *校验失败怎么办*：说明卡有坏块或读卡器不稳。**必须重烧，别抱侥幸** —— 侥幸的结果就是 §0.2 那种"烧录显示成功、启动却找不到 root"。
5. **烧完立刻弹出 TF 卡**（Etcher 会提示 "Flash Complete!"）；
   - *在干吗*：把卡从 Windows 的管辖里摘出来，让它不再被系统"顺手"动到。
6. **别在 Windows 上做任何后续操作** —— 如果 Windows 弹"是否格式化此盘"、"驱动器需要修复"、"扫描"之类的弹窗，**一律点「取消」/「关闭」**。
   - *为什么*：见 §0.2。Windows 看到一个"有 GPT 头但分区不合法"的磁盘，会"好心"重新生成一张空 GPT，把刚才写进去的内容盖掉。一旦格式化，系统就没了 —— **这是新手最常见的翻车点**。

**完成标志**：Etcher 显示 `Flash Complete!`，而且你**一次都没点过** Windows 的格式化/修复弹窗。

**卡住了怎么办**：见 §0.2 的三选一（换 Radxa OS + Etcher 已是最优解）；若 Etcher 写一半报错，换读卡器或换卡再试。

### 4.4 【动手】插卡回板子 → 供电 → 上电

1. TF 卡插进板子卡槽 → **按到底，听到"咔哒"一声锁牢**（再按一下能弹出来那种）；
   - *在干吗*：给板子装上它的"硬盘"。**没插到底 = 没有硬盘** → 板子会掉进 initramfs 报 `No such file or directory`（§0.1 / §0.6 的正面复现）。
2. USB 2.0 OTG / PWR 口接 **PD 头 + 粗 Type-C 线**；
   - *为什么是这两个口里的 OTG/PWR*：见 §3 —— 另一个 USB 3.0 Host 口电流能力弱，**别拿它供电**。
   - *为什么要"粗线 + 大电流头"*：见 §0.1。RK3566 的 SD 控制器在电流不足时**根本起不来**，表现是"板子亮、有输出、但卡一个设备节点都没有"，极难往电源上想。电压 5V 不会烧，电流越大越安全。
3. Micro-HDMI 接显示器；
   - *在干吗*：第一次开机必须有"眼睛"。没显示器就只能靠串口猜，出问题几乎没法查（你之前 initramfs 卡一下午，就是因为屏幕上有线索但不知道怎么看）。
4. 上电 → 等 **30~60 秒**；
   - *为什么慢*：首次启动要做一堆一次性动作 —— 扩展 rootfs 到整张卡、生成 SSH host key、生成 machine-id、初始化 KDE 用户目录。**第一次慢是正常的，慢到 2 分钟也别拔电。**
5. **预期出现 KDE 桌面**（不是命令行！是图形桌面）。
   - *这说明什么*：**能进桌面 = 电源、SD 卡、烧录、设备树四关全过**。到这里为止的踩坑史（§0.1~§0.3）就全部越过去了。

**首次登录凭据**：

- Radxa OS 出厂默认账号：**用户名 `radxa`，密码 `radxa`**（登录后会强制让你改密码，随便改一个就行，先记住）。

**卡住了怎么办**：

| 你看到的 | 说明什么 | 去哪 |
| --- | --- | --- |
| 黑屏 / 无 HDMI 输出 | 板子没起来，或线/显示器接口不对（注意是 **Micro**-HDMI） | 先换线换屏；仍不行查 §0.1 电源 |
| 掉进 `initramfs` / `(initramfs)` 提示符 | 卡没读到、或分区表坏了 | §0.6 的三种情况对照表 |
| 一直停在 Radxa 的启动 logo | 卡读到了但 rootfs 挂不上 | §0.2（烧录被 Windows 干扰） |
| 进了命令行而不是桌面 | 可能是 KDE 启动失败 | 先用命令行继续（后面 §5 照样能走），再查 `journalctl -b` |

---

## 5. 用 SSH 登录（从此不需要键鼠显示器）

**整节在干吗**：把"必须坐在板子跟前接键鼠"变成"从 Windows 远程敲命令"。SSH = 从你 Windows 电脑远程登录板子的命令行。Windows 10/11 自带 `ssh` 和 `scp`，不需要装任何东西。

**为什么必须做**：板子最终要 headless 装在鸭子身体里（25cm、800g，不可能挂个显示器），而且后面每一步（拷脚本、跑安装、看日志）都在板子上敲。做完这一节，HDMI 线和键盘就可以永久撤掉了。

**本节顺序不能乱**：5.1 连网 → 5.2 拿 IP → 5.3~5.4 装公钥 → 5.5 验证。中间任何一步跳了，后面都连不上。

### 5.1 【动手】板子上先确认连上 Wi-Fi

> **在干吗**：让板子自己有网。3W **没有网口**，联网只有 Wi-Fi 一条路；没网就没有 IP，没有 IP 就没有 SSH。
> **完成标志**：网络图标显示已连接，或 `nmcli -t -f DEVICE,STATE device status` 里 `wlan0:connected`。

如果 Radxa OS 没自动连 Wi-Fi，手动连（两种方式任选）：

- **图形方式**：任务栏右下角网络图标 → 选你的 Wi-Fi → 输密码；
- **命令行方式**：在 Konsole 终端（KDE 自带，左下角应用菜单搜 Konsole）里跑：
  ```bash
  sudo nmcli device wifi connect "你家WiFi名" password "密码"
  ```

> **如果命令行连不上、或 SSID/密码里有中文**：用 `nmtui`（全键盘操作的界面，能避开中文 IME 的坑）：
> ```bash
> sudo nmtui
> ```
> 进去后选 **Activate a connection** → 选中你的 Wi-Fi → 输密码。
> ⚠️ 注意：`nmtui` 的 **Activate a connection 只是"连一次"**，想让它开机自动连，得进 **Edit a connection** 把 `Automatically connect` 勾上 `[X]` —— 但更推荐直接用 §0.7 的 `nmcli connection modify` 一条命令搞定。

> ⚠️ **连上之后，务必先做 §0.7 的那次检查**（`grep psk-flags /etc/NetworkManager/system-connections/*.nmconnection`）。
> 如果密码被存成了"用户密钥环"（`psk-flags=1`），那么你在 §6 屏蔽掉 sddm（图形登录）之后，**板子重启就再也连不上 Wi-Fi、SSH 直接失联**，只能抱显示器键盘去救。**这一步必须在屏蔽 sddm 之前做完。**

### 5.2 【只读】知道板子的 IP 地址

> **在干吗**：问板子"你在局域网里的门牌号是多少"。后面所有 `ssh` / `scp` 命令都要填这个地址。
> **为什么是 wlan0**：3W 只有无线网卡，所以地址一定在 `wlan0` 上（有线是 `eth0`，你没有）。

在板子的 Konsole 里：

```bash
ip addr show wlan0
```

找 `inet` 后面那串地址（形如 `192.168.31.30` 或 `192.168.1.42`），**记下来**。

也可以去路由器后台（比如 `http://192.168.31.1`）的 DHCP 租约表里看"已连接设备"。

> ⚠️ **这个地址会变**：路由器按 DHCP 分配，重启路由器/隔几天不看，板子可能就换成别的地址了。**SSH 突然连不上、但板子明明开着** —— 第一件事是去路由器后台重新看它的地址，别急着怀疑板子坏了（§11 速查表里也有这条）。

**完成标志**：你能背下 / 贴出这个 IP。

### 5.3 【动手】Windows PowerShell 里生成 SSH 密钥（一次性）

> **在干吗**：造一对"钥匙"。SSH 免密登录的原理是**非对称加密** —— 生成一对数学上配对的密钥：
>
> | 文件 | 放哪 | 作用 |
> | --- | --- | --- |
> | `id_ed25519`（**私钥**） | 留在你的 Windows，**永远不要给任何人** | 相当于钥匙本身 |
> | `id_ed25519.pub`（**公钥**，`.pub` 结尾） | 拷给板子 | 相当于锁芯：板子拿它来验证"敲门的人手里有没有配对的钥匙" |
>
> 所以下面拷过去的**永远是 `.pub` 那个文件**，别拷错。
> **为什么用 ed25519**：现代默认算法，比老式的 RSA 更短、更快、更安全，Windows/Linux 都原生支持。

打开 **Windows PowerShell**（不是 CMD）：

```powershell
ssh-keygen -t ed25519
```

一路回车（提示保存路径回车、passphrase 回车设为空），会在 `C:\Users\你的用户名\.ssh\` 生成 `id_ed25519.pub`（公钥）和 `id_ed25519`（私钥）。

> **passphrase 为什么留空**：留空 = 用私钥时不再要你输密码，后面的脚本才能自动连。如果你在意安全，可以设一个，但那样每次 `ssh`/`scp` 都要手输一次，后面的自动化步骤会卡住。

**完成标志**：`C:\Users\刘\.ssh\` 目录下出现了 `id_ed25519` 和 `id_ed25519.pub` 两个文件。

### 5.4 【动手】把公钥放进板子（**别用 PowerShell 管道，容易报错**）

> **整节在干吗**：把 5.3 生成的公钥"登记"到板子的 `~/.ssh/authorized_keys` 里。这个文件就是板子的"白名单"：里面列了谁的钥匙可以直接进来。
> **为什么不一步到位**：因为此刻你还没有免密 —— **先用密码把公钥送进去，之后才能免密**。这是先有鸡后有蛋的顺序。

#### 步骤 1：scp 拷公钥文件到板子的 /tmp

> **在干吗**：`scp` = "走 SSH 通道的文件拷贝"（secure copy）。它连过去时用的还是**密码**认证。
> **为什么先落到 `/tmp`**：`/tmp` 是临时目录，谁都能写，不需要额外权限；真正"安装"公钥的动作（下一步）要有正确的权限和目录结构，在板子上做更稳。

```powershell
# 把下面的 <板子IP> 换成你刚查到的地址（比如 192.168.31.30）
scp "C:\Users\刘\.ssh\id_ed25519.pub" radxa@<板子IP>:/tmp/
```

- 首次连接会提示 `Are you sure you want to continue connecting` → 输入 `yes` 回车；
  - *这是在干吗*：SSH 在问"这台板子的指纹我没见过，你确定这是你的板子吗"。第一次当然是 `yes`，之后它会记到 `known_hosts` 里，不再问。
- 提示输入板子密码 → **输入 `radxa`**（或你登录时改后的那个密码）；
- 没输出就表示成功。

> ️ **别用 `type xxx.pub | ssh ...` 这种管道写法**：见 §0.4 —— PowerShell 的管道 + 环境变量 + 中文用户名（"刘"）三个因素叠在一起会报 `Get-Content : 无法将参数绑定到"Path"`。`scp` 一个命令绕开全部问题。

#### 步骤 2：ssh 密码登录板子

> **在干吗**：进板子的命令行，准备做"登记"。

```powershell
ssh radxa@<板子IP>
```

- 输入密码 → 进去后看到 `radxa@radxa-zero3:~$` 提示符；

#### 步骤 3：在板子上把公钥装进 authorized_keys（3 行）

> **在干吗**：逐行解释这三条 ——
> 1. `mkdir -p ~/.ssh`：建 `~/.ssh` 目录，`-p` 表示"已存在就别报错"（幂等）；
> 2. `cat /tmp/id_ed25519.pub >> ~/.ssh/authorized_keys`：把公钥**追加**到白名单里。**注意是 `>>` 不是 `>`** —— `>` 会**清空重写**，如果你以后再加第二台电脑的钥匙，用错符号会把第一把删掉；
> 3. `chmod 600 ~/.ssh/authorized_keys`：把权限收紧成"只有你自己能读"。**这一步不是可选的** —— `sshd` 出于安全会**主动拒绝**权限过宽的密钥文件，表现为"公钥明明放进去了却还要密码"，极难查。

```bash
mkdir -p ~/.ssh
cat /tmp/id_ed25519.pub >> ~/.ssh/authorized_keys
chmod 600 ~/.ssh/authorized_keys
```

- 每行回车，**没任何输出就是成功**；

#### 步骤 4：退出板子

```bash
exit
```

### 5.5 【动手】测试免密登录

> **在干吗**：验证 5.4 登记进去的公钥真的生效了 —— 不用密码直接进去。

回到 Windows PowerShell：

```powershell
ssh radxa@<板子IP>
```

**如果直接进 `radxa@radxa-zero3:~$`，不再要密码 → 完美！** 之后所有远程操作都从这个窗口敲命令就行。

**完成标志**：`ssh` 不提示 `radxa@<IP>'s password:` 就直接进去了。

**卡住了怎么办**：

| 现象 | 原因 | 修法 |
| --- | --- | --- |
| 仍要密码 | 公钥没进去 / 权限太宽 | 在板子上看 `cat ~/.ssh/authorized_keys` 有没有那行；`ls -l ~/.ssh/authorized_keys` 是不是 `-rw-------` |
| 仍要密码，且你重刷过系统 | 板子重建过 host key，Windows 记住了旧的 | `ssh-keygen -R <板子IP>` 清掉旧记录再连 |
| `Permission denied (publickey)` | 拷过去的是私钥不是公钥，或内容被截断 | 重做步骤 1，确认文件名以 `.pub` 结尾 |

**为什么必须配免密 SSH**：不只是为了少打字 —— ① 后面的 `provision` 脚本会让板子重启并自己重连，密码登录没法在重启后自动重连；② 本节之后每一个命令都要跨机器执行，每次手输密码会让你在几十个步骤里疯掉。

---

## 6. 板级环境配置（bring-up）——**先跑诊断再动手**

> **Radxa OS 和 Armbian 有差异（很重要）**：setup-board.sh 硬编码了启动配置文件叫 `/boot/armbianEnv.txt`（Armbian 特有）。Radxa OS 上**没有这个文件**，它用的是 `/boot/extlinux/extlinux.conf`（外加一个 `/boot/uEnv.txt`）。**先诊断再动**，别盲目跑脚本。

**整节在干吗**：把"一块能上网的 Linux 板子"变成"一块能跑机器人的板子"。就三件事：

1. **让硬件设备节点出现** —— `/dev/ttyS2`（舵机总线）、`/dev/i2c-imu`（IMU）这类节点**不是插上就有**。RK3566 的每个外设控制器都要在**设备树**里被显式打开（UART2 还要选引脚复用 mux），这一步叫 **overlay（设备树叠加）**；
2. **让这些设备不被别人占着** —— UART2 出厂是**内核调试串口**，内核日志会往这条线上写，而这条线正好就是舵机总线，舵机的回复会被冲掉；
3. **装上跑策略的运行时** —— **ONNX Runtime**（`robotd` 加载 `.onnx` 神经网络走路要靠它）。

**为什么"先诊断"**：上面这些事在 Armbian 和 Radxa OS 上的做法不一样（配置文件不同、包名不同、overlay 目录不同）。诊断是**只读**的，零风险；先看清现状，能省掉"脚本报错 → 猜 → 乱改 → 板子开不了机"的循环。

**本节完成标志**（全部满足才进 §7）：

| 检查 | 期望 |
| --- | --- |
| `ls -l /dev/ttyS2` | 节点存在 |
| `sudo fuser -v /dev/ttyS2` | **没有任何进程占着**（有 agetty 就是没配好） |
| `ls /usr/local/lib/libonnxruntime.so*` | 存在 1.28.0 |
| `ls ~/install.sh ~/team.dev.pub` | 都在 |

### 6.1 【只读】先跑 7 条诊断（SSH 进去板子后敲）

> **在干吗**：不改变任何东西，只问板子 7 个问题。每个问题对应后面一个"要做 / 要跳过"的决定。

```bash
# ① 启动配置文件叫什么？setup-board.sh 找的是 armbianEnv.txt
ls -la /boot/*.txt /boot/extlinux/extlinux.conf 2>/dev/null

# ② 内核版本 & 板子型号
uname -a
cat /proc/device-tree/model 2>/dev/null; echo

# ③ NetworkManager 有没有？Radxa OS 大概率已经有了
command -v nmcli && nmcli -t -f DEVICE,STATE device status

# ④ /dev/ttyS2 有没有（UART2，舵机总线）——关键检查
ls -l /dev/ttyS* /dev/ttyAMA* 2>/dev/null

# ⑤ systemctl 能跑不
systemctl --version | head -1

# ⑥ 内核启动参数里，调试控制台还挂在串口上吗？（决定要不要手动改）
cat /boot/uEnv.txt 2>/dev/null
cat /proc/cmdline

# ⑦ 舵机总线上有没有 getty 在抢（最阴的一个坑）
systemctl is-enabled serial-getty@ttyS2.service 2>/dev/null; systemctl is-active serial-getty@ttyS2.service
```

**每条在判什么**：

| 条 | 看什么 | 会决定什么 |
| --- | --- | --- |
| ① | 有 `armbianEnv.txt` 还是没有 | 没有 → setup-board.sh 的 overlay 步会跳过，得自己动 `extlinux.conf` |
| ② | 内核版本；`model` 串**只是通用串 `Radxa ZERO 3`，不带 W/E 后缀**，别拿它认型号（见 §1） | 只作记录 |
| ③ | `nmcli` 在不在、`wlan0` 是不是它管 | 在 → §6.5 网络迁移**整节跳过** |
| ④ | `/dev/ttyS2` 在不在 | 在 → overlay 已经好了（比如你已在 `rsetup` 里加过 `rk3568-uart2-m0.dtbo`） |
| ⑤ | systemd 版本 | 只作记录 |
| ⑥ | `/proc/cmdline` 里有没有 `console=ttyS0 / ttyFIQ0 / ...` | **有 → 内核日志正在污染舵机总线，必须改** |
| ⑦ | ttyS2 上有没有 getty | `active` → 必须 mask 掉（setup-board.sh 会做） |

> ⚠️ **⑥ 的坑**：Radxa OS 出厂把调试控制台放在 UART2（`console=ttyFIQ0,1500000n8`）。你把它当舵机总线用之前，必须把 `console=` 改到屏幕（`tty1`）并**删掉 `earlycon`** —— 改的是 `/boot/extlinux/extlinux.conf` 里 `append` 那一行。**改完必须重启才生效。**

#### 你这块板子的实测结果（2026-09-15，可作为对照）

| 条 | 实际输出 | 意味着 |
| --- | --- | --- |
| ① | 有 `extlinux.conf` + `uEnv.txt`，**没有** `armbianEnv.txt` | 脚本 overlay 步会 warn 跳过 —— **这是预期行为，不是故障** |
| ② | `6.1.84-10-rk2410-nocsf` / `Radxa ZERO 3` | Radxa 的 vendor 内核；型号串不带后缀 |
| ③ | `/usr/bin/nmcli`；`wlan0:connected` | **§6.5 跳过** |
| ④ | `/dev/ttyS1` + `/dev/ttyS2` 都在 | overlay 已就绪 ✅ |
| ⑤ | `systemd 252` | 够用 |
| ⑥⑦ | 取决于你有没有改过 `extlinux.conf` / mask 过 getty | 没改就必须补 |

### 6.2 【动手】获取脚本并放到板子上

> **在干吗**：板子是**独立的电脑**，上面没有你 Windows 里的仓库。这一步把要在板子上执行的脚本"送过去"。
> **为什么用 `scp` 而不是让板子自己从 GitHub 下**：① 走局域网，几 MB 秒传，不受 GitHub 在国内的速度影响；② 这仓库若是**私有的**，板子上的 `curl` 会拿到 **404**（GitHub 对私有路径返回 404 而不是 401，看着像网址写错了）；③ 你本地本来就有这份代码。

在你的 Windows 主机（项目已有仓库 `E:\optiDuck\joyandai\microduck`），用 PowerShell：

```powershell
cd E:\optiDuck\joyandai\microduck

# 把 setup-board.sh / migrate-network.sh / install.sh + dev key 拷到板子家目录
scp scripts\setup-board.sh scripts\migrate-network.sh radxa@<板子IP>:~/
scp scripts\install.sh deploy\dev-key\team.dev.pub radxa@<板子IP>:~/
```

（`~` 表示板子的家目录 `/home/radxa`）

**这四个文件分别是干嘛的**：

| 文件 | 用途 | 你这次用不用 |
| --- | --- | --- |
| `setup-board.sh` | §6.4 的板级 bring-up：mask getty、装 ONNX Runtime、打印体检报告 | ✅ **必须** |
| `migrate-network.sh` | 把网络从 netplan 迁到 NetworkManager | ❌ 你已经是 NM，用不到（拷过去无害，脚本自己会退） |
| `install.sh` | §7 装 microduck 守护进程（robotd 等） | ✅ 下一步就用 |
| `team.dev.pub` | 让这块板子成为**"开发板"**：信任团队 dev 签名，之后能装分支构建 | ✅ 建议装 |

**完成标志**：`ls -l ~/setup-board.sh ~/migrate-network.sh ~/install.sh ~/team.dev.pub` 四个文件都在。

**卡住了怎么办**：`No such file or directory` 且提示的是 **Windows 这边**的路径 → 先在 PowerShell 里 `dir scripts\setup-board.sh` 确认文件真的在（Windows 文件名不区分大小写，但 `scp` 传到 Linux 后区分）。

### 6.3 【动手】第一次：建用户组（先于重启）

> **在干吗**：建一个系统用户组 `robot`，并把你自己加进去。
> **为什么需要**：这套软件要让**普通用户**（`radxa`）能操作机器人（跑 `robotctl`、看日志、重启服务），但不该把你变成 root。做法就是：设备节点和服务归 `robot` 组管，`radxa` 在组里 → 你只获得精确的那几个权限。
> **为什么叫"第一次"、为什么必须"先于重启"**：`usermod -aG` 加组**只对新的登录会话生效** —— 加完得重新登录 / 重启，`id` 里才会出现 `robot`。

```bash
sudo groupadd --system robot
sudo usermod -aG robot "$USER"
```

**完成标志**：现在跑 `groups` 可能还看不到 `robot`（正常）；重启后 `groups` 里出现 `robot` 才算成。
**卡住了怎么办**：`groupadd: group 'robot' already exists` → 无害，说明之前建过，继续往下。

### 6.4 【动手】运行 `setup-board.sh`

> **在干吗**：官方给的"板级一次性配置"脚本。它设计成**幂等**（重复跑安全）、**绝不自己重启**（需要重启时会告诉你然后停下）。
> **为什么是 `sudo sh` 而不是 `./setup-board.sh`**：它要改 `/boot` 下的启动配置、mask 系统服务、往 `/usr/local/lib` 装库 —— 全是 root 才能做的事；而且这个镜像上的 `/tmp`、家目录挂载可能带 `noexec`，用 `sh` 显式执行最稳。
> **为什么它不删自己**：第一次跑时它会把自身复制到 `/usr/local/sbin/robot-setup-board`。因为它的工作恰恰是"改配置 → 重启 → 再确认"，而 `/tmp` 重启就没了 —— 一个跨重启的脚本把自己删掉是个恶劣玩笑。
>
> 📖 **下面这张表是"跑完看结果"用的。如果你想彻底搞懂它内部每一步的原理、作者为什么这么设计、以及怎么把这套方法用在别的板子上 —— 直接看 [§6.6 逐段精读](#66-只读setup-boardsh-逐段精读原理篇为什么每一步长这样) 和 [§6.7 方法论](#67-方法论换一块新板子--换个新机器人怎么自己设计-bring-up)。**

```bash
sudo sh ~/setup-board.sh
```

**它按顺序做这些事**（最后一列是它在**你这块 Radxa OS 上**的实际结果）：

| 步骤 | 做什么 | 为什么 | 在你这块板子上 |
| --- | --- | --- | --- |
| `check_environment` | 检查 root / aarch64 / `curl tar find install` 齐不齐 | 最早失败最省时间 | ✅ |
| `persist_self` | 把自己复制到 `/usr/local/sbin/robot-setup-board` | 见上 | ✅ 成功 |
| `check_network` | 只读：`nmcli` 在不在、`wlan0` 归谁管 | 提醒 `configd` 需要 NetworkManager | ✅ 报"已连接"，无动作 |
| `configure_overlay` | 在 `armbianEnv.txt` 里设 `overlay_prefix=rk3568`、加 `overlays=uart2-m0 i2c4-imu` | 让设备树能加载，否则 `/dev/ttyS2`、`/dev/i2c-imu` 都不存在 | ⚠️ **warn 跳过**（找不到 `armbianEnv.txt`）。**你已用 `rsetup` 加过 `rk3568-uart2-m0.dtbo` / `rk3568-i2c4-m0.dtbo`，等效** |
| `free_motor_port` | mask `serial-getty@ttyS2.service`；把内核 `console=` 从串口挪到屏幕 | 别让登录终端 / 内核日志吃掉舵机回复 | ✅ **mask 这半段会生效、而且有用**；`console=` 那半段跳过（要自己改 `extlinux.conf`，见 6.1 ⑥） |
| `configure_audio` | 装 `alsa-utils/device-tree-compiler/dkms/gcc/make/i2c-tools`，再装 Armbian 的 vendor 内核包 | 音频 codec 的驱动在 vendor 内核里 | ⚠️ 前半段能装成；后半段 **Radxa OS 源里没有那些包 → warn `could not install the vendor kernel — audio will not work`**。**音频放弃，不影响走路** |
| `configure_tof` | 写 `/dev/i2c-pihat` 的 udev 规则 | 深度传感器要固定名字 | ⚠️ 只写规则（无害），但 i2c3 总线可能没开 |
| `configure_camera` | 找 `*/rockchip/overlay` 目录，装摄像头 overlay | 摄像头要开 CSI/I²S | ⚠️ Radxa OS 的 dtbo 在 `/boot/dtbo/`，路径对不上 → warn 跳过 |
| `configure_imu` | 装 IMU 的 overlay | i2c4 上的 LSM6DSV16X | ⚠️ 同上 warn 跳过（**你的 i2c4 已由 rsetup overlay 开好**） |
| `install_onnxruntime` | 从 GitHub 下 ONNX Runtime **1.28.0**（aarch64）装进 `/usr/local/lib` + `ldconfig` | `robotd` 靠它加载 `.onnx` 策略 | ✅ **唯一真正关键的一步**。⚠️ **下载失败脚本会直接 `die` 退出**，见下表 |
| `report` | 打印 board status | 一眼看出还缺什么 | ✅ |

**预期你会看到 4~6 条 warning**，全部是 Radxa OS 与 Armbian 的差异导致的**误报**，不用管。

脚本末尾会打印 **board status**。重点看：

- `motor bus /dev/ttyS2 present` → 好消息；
- `ONNX Runtime ABSENT` → 没装上，见下表；
- `wifi NetworkManager, connected` → 正常；
- 末尾 `reboot required` → 有改动要重启才生效，**重启前先确认 §0.7 的 Wi-Fi 自动连已经修好**。

**卡住了怎么办**：

| 现象 | 原因 | 修法 |
| --- | --- | --- |
| 卡在下载 ONNX Runtime / curl 报错、脚本退出 | 国内访问 GitHub releases 慢或被断 | 直接**重跑一次**（脚本幂等）；仍不行就手动装：在能上网的机器下 `onnxruntime-linux-aarch64-1.28.0.tgz`，`scp` 到板子解压，把 `lib/` 里的 `libonnxruntime.so*` 拷进 `/usr/local/lib`，再 `sudo ldconfig` |
| `could not install the vendor kernel — audio will not work` | Radxa OS 没有 Armbian 的包 | **正常，忽略**（除非你要音频） |
| `no rockchip overlay directory under /boot` | Radxa OS 的 dtbo 路径不同 | **正常，忽略**（你的 uart2/i2c4 已开好） |
| 脚本说 `reboot required`，但你没改 Wi-Fi | — | **先看 §0.7**，否则重启即失联 |

**完成标志**（就是 §6 开头那张表）：
```bash
ls -l /dev/ttyS2 /dev/i2c-imu
sudo fuser -v /dev/ttyS2          # 期望：无输出（没有任何进程占着）
ls /usr/local/lib/libonnxruntime.so*
```

### 6.5 【动手】网络迁移：netplan → NetworkManager（**你这块板子：跳过**）

> **在干吗**：Armbian 出厂用 **netplan + systemd-networkd + wpa_supplicant** 管网络；这套软件要求用 **NetworkManager**。这个脚本就是一次性迁移。
> **为什么要换（而不是"能用就行"）**：netplan 是**配置生成器**，不是网络管理器 —— 它**没有扫描 API**，`netplan apply` 只会说"配置已应用"，不会告诉你**到底连没连上**。而手机 App 给机器人配网最需要的两件事恰好是"给我看看有哪些网络"和"这个密码错了"。NetworkManager 才有这些能力。
> **为什么这步特别标注危险**：它是**唯一能让 headless 板子直接失联**的一步 —— 换网络栈如果出错，SSH 就永远回不来，必须抱显示器键盘去救。所以它被**单独拆成一个脚本**，而不是塞在 `setup-board.sh` 里。

**你的情况：跳过本节。**

理由（§6.1 ③ 的实测）：`nmcli` 存在、`wlan0:connected` —— 这块 Radxa OS 出厂就是 NetworkManager，没什么可迁的。

> 如果以后你换回 Armbian 镜像，则要跑（模式是"**重启前后各跑一次**"）：
> ```bash
> sudo sh ~/migrate-network.sh
> sudo reboot
> # 重启后 SSH 回来，再跑一次，用来撤销兜底配置
> sudo /usr/local/sbin/robot-migrate-network
> ```
>
> 它是"重启前后各跑一次"的两段式：第一次改配置并留下一个**兜底**（万一网络没起来就自动回滚），重启后再跑一次**退掉兜底**。**看不懂也没关系 —— 你这块板子不用它。**

### 6.6 【只读】`setup-board.sh` 逐段精读（原理篇：为什么每一步长这样）

> **这一节不讲"敲什么命令"，只讲"脚本里到底发生了什么、作者为什么这么设计"。**读完之后，你换一块新板子（甚至换一款机器人），也能自己把 bring-up 流程设计出来。

#### 6.6.0 先看它的"宪法"：6 条设计原则

脚本 [setup-board.sh](file:///e:/optiDuck/joyandai/microduck/scripts/setup-board.sh) 开头几乎没有代码，全是注释在争论"为什么"。那些争论就是它的设计原则 —— **理解了这 6 条，整份脚本就没有黑箱了**：

| # | 原则 | 具体做法 | 为什么必须这样 |
| --- | --- | --- | --- |
| 1 | **只管"板子"，不管"软件"** | 它和 `install.sh` 是**两个**脚本 | 见下面单独展开 |
| 2 | **幂等**（重复跑安全） | 每一步都是"**先检查，再决定改不改**"，绝不直接写 | 它自己的工作就是"改配置 → 重启 → 再确认"，**必然要跑第二遍**；不幂等的话第二遍会毁掉第一遍的成果 |
| 3 | **绝不自作主张重启** | 只设一个变量 `needs_reboot=1`，最后打印"该重启了"然后**自己结束** | 重启会瞬间切断 SSH。脚本**没有资格**替你决定让板子失联 —— 这个决定必须由拿着板子的人做 |
| 4 | **先把自己存下来** | `persist_self`：复制自己到 `/usr/local/sbin/robot-setup-board` | `/tmp` **不跨重启**。一个"改启动配置 → 重启 → 再确认"的脚本，重启后把自己删掉，是"对你手里这块板子的恶劣玩笑" |
| 5 | **非核心功能一律"软失败"** | 音频 / 摄像头 / ToF / 蓝牙全部"出错就 `warn` 然后继续"；只有电机总线是硬需求 | **能走路的板子 > 样样完美的板子。**没有音频的鸭子走得和好的一模一样，所以音频**不允许**中断 provisioning |
| 6 | **只打印命令，不替你执行** | `fetch_cmd` 只 `printf` 一行 `curl` 命令给你看 | ① 脚本自己只从**公开**地址下一样东西（ONNX Runtime），不需要 token；② 打印的 token 写成 `$DUCK_TOKEN` **变量名**而不是值 —— 因为 **bring-up 日志会被贴进聊天/issue**，泄露的 token 得挨个板子轮换 |

**第 1 条展开看（这是整份架构最重要的一刀）**：

| | `setup-board.sh` | `install.sh` |
| --- | --- | --- |
| 管什么 | 操作系统层 bring-up：设备树 overlay、ONNX Runtime | 装一个**签名**的守护进程 release |
| 属于谁 | **板子** | **软件** |
| 多久变一次 | 极少变 | **每次更新都装** |
| 要重启吗 | 要（overlay 要重启才生效） | 不要 |
| 需要 root | 是 | 是 |
| 高风险操作 | 有（改启动配置） | 有（改网络栈是单独脚本） |

> **如果不拆开会怎样**：每次软件更新都要重新讨论一遍启动配置。overlay、内核 console 这些**和软件版本毫无关系**的东西，会被卷进"更新"里反复处理。**"频率不同、生命周期不同、风险不同"的东西，就该是两个脚本。**

#### 6.6.1 先读 `main()`：调用顺序就是整个流程

```sh
main() {
    check_environment        # ① 是不是 root / aarch64 / 工具齐不齐
    persist_self             # ② 把自己复制到 /usr/local/sbin（跨重启）
    configure_overlay        # ③ 打开 UART2（舵机总线）+ i2c4（IMU）的设备树开关
    check_network            # ④ 只读：Wi-Fi 归谁管
    free_motor_port          # ⑤ 把登录终端和内核 console 从舵机串口上赶走
    configure_bluetooth      # ⑥ 手柄配对需要的 BlueZ 设置（默认什么都不动）
    configure_audio          # ⑦ 音频 codec：5 层，可失败，顺带装 vendor 内核
    configure_tof            # ⑧ 头部深度传感器的稳定设备名
    configure_camera "${vendor_ver:-}"   # ⑨ 摄像头 overlay（要 ⑦ 装的 vendor 内核）
    configure_imu    "${vendor_ver:-}"   # ⑩ IMU overlay + 稳定设备名（同样要 ⑦）
    install_onnxruntime      # ⑪ 跑走路策略的运行时
    report                   # ⑫ 体检报告（只读）
}
```

**这个顺序不是随便排的，有两处硬依赖**：

- **⑦ 必须在 ⑨ 之前** —— 音频那步会装 **Armbian vendor 内核**，而摄像头的 MIPI-CSI 采集驱动和 overlay 目录（`/boot/dtb-<ver>/rockchip/overlay`）**只存在于 vendor 内核那个分支**。所以 ⑨⑩ 要拿 ⑦ 算出来的 `vendor_ver`。这就是 `configure_camera "${vendor_ver:-}"` 那个参数的意义。
- **③ 必须在 ⑤ 之前**，而且 ③ 和 ⑤ 都改同一个文件（`armbianEnv.txt`），但改的是**不同变量**（overlay 相关 vs `console=`）—— 分开写是为了两份逻辑互不干扰。

#### 6.6.2 逐段精读：每一段在干什么

##### ① `check_environment` —— 三道门

```sh
[ "$(id -u)" = 0 ] || die "run as root — re-run that same command with sudo"
[ "$arch" = aarch64 ] || die "this targets aarch64 boards, and this box is ${arch}"
for tool in curl tar find install; do command -v "$tool" || die "${tool} is required"; done
```

**在干吗**：检查四个必须条件 —— root（要改 `/boot`、mask 服务）、aarch64（二进制架构）、`curl`/`tar`（下 ONNX 并解包）、`install`（带权限的复制，比 `cp`+`chmod` 更原子、更简洁）。

**为什么放最前面**：**最早失败 = 最省时间**。四件事里任何一件不满足，后面 11 步全是白做。

> ⚠️ 注意报错消息里**故意不写文件路径** —— 只说"你刚才敲的那条命令，前面加 `sudo`"。因为写死路径的话，一旦脚本被复制到别处（**而这正是 `persist_self` 干的事**），建议就和现实不符了。

##### ② `persist_self` —— "先把自己存下来"

```sh
case "$0" in
    sh|-sh|bash|-bash|/dev/fd/*|/proc/self/fd/*) return 0 ;;   # 管道进来的，没有文件可存
esac
if [ "$(readlink -f "$0")" = "$(readlink -f "$SELF")" ]; then persisted=1; return 0; fi
install -m 0755 "$0" "$SELF" && persisted=1
```

**在干吗**：把自己复制到 `/usr/local/sbin/robot-setup-board`。

**三个细节，每个都有原因**：

1. **`case "$0"` 那一行**：如果你是用 `curl ... | sudo sh` 跑的，那 `$0` 就是 `sh` 本身，**磁盘上根本没有这个文件**，无从复制。所以先判断"我是被管道喂进来的吗"，是就直接跳过。
2. **`readlink -f` 比较**：如果当前就是**从已安装的副本**跑的，那"复制到自己身上"会把文件**截断成 0 字节**。必须先判断"来源和目标是同一个文件吗"。
3. **`persisted` 这个标志**：它决定 `report` 最后打印哪种"重启后怎么继续"的提示 —— 存下来了就让你跑 `sudo /usr/local/sbin/robot-setup-board`；没存下来（管道版）就**连 `curl` 命令一起打出来**，因为 `/tmp` 会被这次重启清空，而你的 shell 历史里也没有那条命令。

##### ③ `configure_overlay` —— 打开舵机总线和 IMU 的开关

**先理解"设备树 overlay"是什么**：RK3566 有很多个外设控制器（UART、I²C、SPI…），**出厂时大部分是关着的**。要让某个控制器工作，得在启动时加载一小段"补丁"（`.dtbo` 文件），告诉内核"把 uart2 打开、用 m0 这组引脚"。这段补丁就叫 **overlay（设备树叠加）**。

**脚本改的是 `armbianEnv.txt` 里的两行**：

```
overlay_prefix=rk3568          ← 决定"去哪里找 dtbo、拼什么名字"
overlays=uart2-m0 i2c4-imu     ← 要加载哪几个 overlay
```

**它要修的三个坑（都在注释里写了）**：

| 坑 | 现象 | 为什么"最难查" |
| --- | --- | --- |
| Armbian 默认写 `overlay_prefix=rk35xx`，但 dtbo 实际叫 `rk3568-*.dtbo` | **加载器一个都找不到** | 板子**照常启动**、不报错、`dmesg` 也不说，**只是 `/dev/ttyS2` 不存在** |
| `armbian-config` 的 overlay 编辑器在这块板子上直接崩（`Invalid overlay_prefix rk35xx`） | 没法用官方工具改 | 只能直接改文件 —— **这就是为什么它是个脚本，而不是一份"操作清单"** |
| 内核升级会重新指向 `/boot/{Image,dtb,uInitrd}` | 升级后电机突然全不见了 | 所以 `report` 会提醒你"该重启了、再跑一遍" |

**代码上的讲究**：加 overlay 词用的是**追加**（`overlays=已有的 uart2-m0`），不是替换整行 —— 因为**镜像原本开了哪些，不是你该删的**。

**还有一个容易忽略的点**：`overlays=` 里写了**磁盘上不存在的名字**会怎样？启动时**静默跳过**，什么都不说。这就是为什么 `configure_imu` 和 `configure_camera` 必须**先确保 `.dtbo` 真的装上了，才敢往 `overlays=` 里加词**。

##### ④ `check_network` —— 只读，而且故意"不做事"

**它在干吗**：问三个问题 —— ① `nmcli` 在不在（网络归 NetworkManager 还是 netplan）？② `wlan0` 是不是 NM 管的（迁移做完了吗）？③ 迁移脚本留的"兜底重启服务"收掉了吗？

**为什么"迁移"被拆到 `migrate-network.sh` 而不写在这里**（注释给了两条理由，都不是"文件太大"）：

| 理由 | 说明 |
| --- | --- |
| **生命周期不同** | 它只是因为"Armbian 出厂带 netplan"才存在。等哪天做了自带 NM 的镜像，这个脚本**整份删掉**；而 overlay 和 ONNX 是**永远**需要的 |
| **风险不同** | 它是**唯一一个能让 headless 板子永久失联**的步骤。这种事不能塞在"你随便重跑都没关系"的 bring-up 里，必须**拿出来做一次明确决定** |

**为什么还是要检查**：`configd` 是通过 **D-Bus 驱动 NetworkManager** 的。板子还停在 netplan 上时，每个网络调用的回答都是"没有这个设备"。**在 bring-up 阶段说清楚，比以后在别的地方撞上这个怪错误强。**

##### ⑤ `free_motor_port` —— 从舵机串口上赶走两个"占座的人"

**背景**：UART2 是 RK3566 的**调试串口**，所以 Armbian 默认在这条线上跑一个登录终端（`serial-getty@ttyS2`）。

**为什么这是致命问题**：getty **不只是"占着端口"，它会主动读**。舵机回复的字节被 getty 先吃掉了，`robotd` 什么都收不到 → **每个舵机看起来都像不存在** → 和"舵机没插/没上电"**完全无法区分**。

> 脚本注释写得很实在：这不是假想问题 —— 它**耗掉了一个下午**，对着一台接线正确、其它工具都能看到所有舵机的机器人，盯着 `read return_delay_time on 20: Operation timed out` 发呆。**第一个说真话的证据，是 `fuser -v /dev/ttyS2` 报出了 `agetty`。**

**两个"占座的人"，要分别赶**：

| 占座者 | 赶走方式 | 为什么不能用更轻的方式 |
| --- | --- | --- |
| `serial-getty@ttyS2` | **mask**（不是 disable） | `getty.target` 会把它**重新拉回来**。`disable` 只是不自动启动，`mask` 才是"彻底禁止启动" |
| **内核自己的 console**（printk） | 把 `console=both`/`console=serial` 改成 `console=display` | 内核消息和舵机回复**走在同一根线上**。而且它**大部分时间是安静的** —— 所以表现成"没有规律的间歇性总线故障"，**这比一直坏更难查** |

**一句话总结这段的哲学（脚本原话）**：**一根 UART 不可能既是 console 又是电机总线。选择电机总线，就是整个脚本存在的意义。**

> ⚠️ **`console=display` 是 Armbian 专有的写法。** 你这块 **Radxa OS 上没有这个值** —— 要改的是 `/boot/extlinux/extlinux.conf` 里 `append` 那一行的 `console=tty1`（并删掉 `earlycon`），见 §6.1 ⑥。**同一个道理，不同镜像不同写法** —— 这正是"先诊断再动手"的又一个理由，也是你在这块板子上看到 `free_motor_port` "只能做一半"的原因。

##### ⑥ `configure_bluetooth` —— 默认"什么都不做"，这是设计

**先看它的第一段代码**：没给 `--weird-ble` 也没给 `--pause-btd-on-pair`，就直接 `say "leaving bluetooth alone"` 然后返回。

**为什么默认不动**：因为**大部分板子什么都不需要动**。

**那为什么还留这两个开关？** 因为实测发现 Radxa Zero 3W 的蓝牙芯片（aic8800）**在十块板子里大概一半有毛病、另一半没有**，而且**找不到任何可测量的区别** —— 同样的内核版本、同样的 BlueZ、**逐字节相同**的固件；连"曾经被怀疑的驱动构建版本"也对不上。

**最关键是下面这张实测表**（注释里的原始记录，2026-08-19 在一块板子上单变量测出来的）：

| `Privacy` | 配对时暂停 `btd`？ | 结果 |
| --- | --- | --- |
| `off` | 否 | 加密变更后约 **800 微秒**配对就死，报 `Remote User Terminated (0x13)` |
| `off` | **是** | **配对成功**，45/45 次采样都稳，能真实操作、能开 |
| `device` | 是 | 能配上，但**反复掉线**：46 次 `PIN or Key Missing (0x06)` |

**这张表推翻了之前的结论**，得到两条**互相独立**的因果：

1. **`btd` 在广播会破坏"新建配对"** → 配对那几分钟把 `btd` 停掉就好。**这也解释了为什么"换个驱动构建就好了"是错觉** —— 以前所有归咎于驱动的失败，都同时有 `btd` 在广播这个**没被控制的变量**。
2. **`Privacy = device` 会破坏"重连"** —— 在一块**不需要它**的板子上。而且它**失败得比"干脆配不上"更糟，因为它看起来像成功了**（先配上，然后开始掉线）。

**所以两个开关是"修两种不同的病"，不是一个套餐**：

| 开关 | 修什么 | 代价 / 何时用 |
| --- | --- | --- |
| `--pause-btd-on-pair` | 配对时暂停 `btd` | 几乎无代价，**先试这个** |
| `--weird-ble` | 额外设 `Privacy = device` | **在不需要它的板子上有害**，所以不默认开。它**隐含**了上面那个开关 |

**还有一个工程细节值得学**：它在 `/var/lib/robot/weird-ble` 写了一个**标记文件**给 `robotctl` 读，而不是让 `robotctl` 自己去解析 `main.conf`。理由：**"有人明确做过的决定"不能和"某个其它途径来的 `Privacy` 值"混为一谈。**

> 注释里还写了"以后怎么办"：**这两个开关都是在对付一颗"最终不会用"的无线电芯片。芯片一换，两个开关和 `robotctl` 里的 `BtdPaused` 一起删掉。** —— 好代码会写明自己的工作什么时候该结束。

##### ⑦ `configure_audio` —— 五层，全部"软失败"

**它的态度**：注释第一句就是"**这里每一步都是软失败的** —— 没有音频的板子走起来一模一样，所以下面任何一步都不许中断 provisioning"。

**为什么音频这么麻烦（五层缺一不可）**：

| 层 | 做什么 | 为什么少一层就不行 |
| --- | --- | --- |
| 1 | 装 `alsa-utils` / `device-tree-compiler` / `dkms` / `gcc` / `make` / `i2c-tools` | 工具链。顺带：**`i2c-tools` 的 postinst 会创建 `i2c` 用户组** —— 后面的 codec 和 ToF 都在这个总线上，而且 `i2cdetect` 是设备不响时**第一个**要跑的东西 |
| 2 | 装 **Armbian vendor 内核**（image + dtb + headers） | **codec 的 I²S 时钟树只存在于 vendor 分支**。还要 headers 给 DKMS 编译用 |
| 3 | 从 `deploy/audio/` 拉 `.dts` 源文件，用 `dtc -@` 编译成 `.dtbo` 装进 overlay 目录，再把词加到 `overlays=` | 硬件 i2c3 总线（排针 3/5），以及**嫁接**到它上面的 codec + I²S 声卡 |
| 4 | 用 **DKMS 编译 codec 驱动**（`aic3x`） | **vendor 内核也不编译 `SND_SOC_AIC3X`** —— 原厂板子根本没有 aic3104 声卡，必须 out-of-tree 自己编 |
| 5 | 装一个开机服务 `aic3104-init.service` 设置混音器电平 | 开机时要把喇叭路径设好、麦克风路由好，才能"开口就出声" |

**两个很"老练"的细节**：

- **DKMS 那步要先修内核头文件**：Armbian 发的 vendor headers **不带已经编好的 host 工具**，而 DKMS 需要 `modpost`。所以它先 `dpkg-reconfigure linux-headers-vendor-rk35xx` 把这块补出来 —— 不修的话，DKMS 构建会以一个**看起来像"你代码写错了"**的方式失败。
- **overlay 词的顺序有讲究**：codec 的 overlay **必须排在它依赖的总线 overlay 之后** —— 因为它是"把 codec 节点嫁接到那个总线节点上"。所以 `ensure_overlay_word` 是**追加**，不是替换。

> **声音本身不在这里做**：注释明确说"**语音资源包不在这里 provisioning**"，由 release 的 postinstall 用自带的 `sounds` 二进制、以 SoC 序列号为种子生成。

##### ⑧ / ⑩ `configure_tof` / `configure_imu` —— 为什么要给设备"改名字"

**先看问题**：Linux 里 I²C 总线叫 `/dev/i2c-3`、`/dev/i2c-4`…… 但**这个编号是内核枚举出来的，会变**。换内核、换 overlay 都可能重新编号。

**解决方式**：写一条 **udev 规则**，按**设备树地址**（一个永不改的硬件标识）给总线起个**稳定别名**：

```
SUBSYSTEM=="i2c-dev", KERNELS=="fe5c0000.i2c", SYMLINK+="i2c-pihat"     # ToF/音频那条
SUBSYSTEM=="i2c-dev", KERNELS=="fe5d0000.i2c", SYMLINK+="i2c-imu"       # IMU 那条
```

**为什么这样就更稳**：`fe5c0000.i2c` 是这颗 SoC 上这个控制器的**设备树地址**，是硬件的身份证 —— **不管它被编号成 i2c-3 还是 i2c-7，别名都指向同一个硬件**。这样 `tofd`、`robotd` 的配置里就能写死 `/dev/i2c-imu`，不用跟着编号变。

**四个看起来很讲究的做法**：

- **两条规则分成两个文件**（`99-robot-i2c-pihat.rules` 和 `99-robot-i2c-imu.rules`）—— 这样它们**互不覆盖**，一条总线一个别名；
- **规则写完立刻 `udevadm control --reload-rules` + `trigger`** —— 这样**已经插着的传感器不用重启就能用**；
- **`udevadm` 失败是 `|| true`** —— 不值得中断 provisioning；
- **IMU 的 overlay 和它的别名规则是"两半"**：一半是编译并安装 `i2c4-imu.dtbo`（否则 `configure_overlay` 加进 `overlays=` 的那个词就是个**磁盘上不存在的名字 → 静默跳过**），另一半才是这条 udev 规则。

##### ⑨ `configure_camera` —— "镜像是同一张，但名字必须加前缀"

**问题**：Armbian 把摄像头 overlay 叫 `radxa-zero3-rpi-camera-v2.dtbo`（**没有** `rk3568-` 前缀），而这块板子跑的是 `overlay_prefix=rk3568`。于是加载器去找 `rk3568-radxa-zero3-rpi-camera-v2.dtbo` → **找不到 → 高高兴兴启动 → 没有摄像头**。

**这和第 ③ 步的 `overlay_prefix` 错误是同一类"静默失败"。**

**修法**：把文件**复制**一份成带前缀的名字。

**为什么是"复制"而不是"软链接"**（值得学的取舍）：Armbian 的包更新会**替换**那个没前缀的文件。软链接会变成**悬空链接**（彻底坏掉），而复制出来的副本**至少还能用**，重跑脚本时再刷新成新的。**在"可能会旧"和"可能会断"之间，选"可能会旧"。**

**它还有一个 `DUCK_CAMERA_OVERLAY` 开关** —— 换别的摄像头模组时改这个变量，而不是改脚本。`radxa-zero3-rpi-camera-v1.3` 是 Pi Cam v1.3 / OV5647（注释老实说"**没测过**"）。

##### ⑪ `install_onnxruntime` —— 唯一真正关键的一步

**先理解这东西是什么、为什么必须单独装**：`robotd` 走路的神经网络（`.onnx` 文件）**不是自己算的**，它要靠 **ONNX Runtime（一个 C++ 库，约 20MB）** 来跑。

**为什么它不是 release 的一部分**：它**变得比 daemon 慢得多**。塞进每个 release，等于**每次更新都白送 20MB 不变的库**。代价是：它是**运行时 `dlopen` 加载的，不是链接进去的** —— 所以**没有它的板子能正常安装、正常启动，然后发现走不了路**。

**这段代码最值得学的是"版本感知"，而不是"存在即跳过"**：

```sh
# 解析 libonnxruntime.so → libonnxruntime.so.1.28.0，取出 1.28.0
if [ "$existing" = "$ONNX_VERSION" ]; then say "already present"; return 0; fi
if [ -n "$existing" ]; then say "replacing ${existing} with ${ONNX_VERSION}"; fi
```

**为什么这个改法是被血换来的**（注释里是原始 panic 信息）：

```
thread 'control' panicked at ort-2.0.0-rc.11/src/lib.rs:191:41:
Failed to load ONNX Runtime dylib: ... expected version >= '1.23.x', but got '1.20.1'
```

- **`ort`（Rust 的 ONNX 绑定）对版本是硬检查、不是警告 —— 它直接 panic**，把 `robotd` 的**控制线程打死**，而不是返回一个错误；
- 所以**光检查"文件在不在"是不够的**：那种写法的板子带上一个不兼容的运行时，**重跑脚本永远修不好**（符号链接存在 → 直接 `return`）。**这正是 1.20.1 那个锁定版本造成的局面。**
- **往上装是安全的**：`ort` 要的是"**至少**它的 API 版本"，而 ONNX Runtime 的 C API **向后兼容**，更高的运行时伺候旧的 API 版本完全没问题。`ONNX_VERSION` 必须和 `Cargo.toml` 里的 `ort` **一起升** —— 注释原话是"**这是同一个决定，而两者只有一个会在编译期被检查到**"。

**还有一个小坑**：`ldconfig` 在 `/usr/sbin`，**常常不在登录用户的 PATH 里**。如果只用 `command -v ldconfig` 判断，会误判成"没有"从而跳过刷新，**结果刚拷进去的库 `dlopen` 找不到**。所以代码是"先试 PATH，再试绝对路径 `/usr/sbin/ldconfig`"。

##### ⑫ `report` —— "这块板子现在到底怎么样"

**为什么它值得单独一段、而且"不管有没有改动都打印"**：因为**"这块板子准备好了吗"本身就是一个值得随时能问的问题**。

**它打印 10 项，每一项背后都是一个真实事故**：

| 打印项 | 判据 | 为什么要单独列 |
| --- | --- | --- |
| **motor bus** | `/dev/ttyS2` 在不在 | **分三种情况**：存在 / "已启用，等重启" / **缺失**。第三种会额外警告"没有任何 overlay 改动待生效，所以是别的地方坏了" |
| **btd on pairing** | 标记文件在不在 | 和下一项配对看，才能判断板子处于三种配置中的哪一种 |
| **bluetooth privacy** | `Privacy = device` 吗 | **每次都要说出后果** —— 因为它就是那个"看起来像成功"的故障 |
| **gamepad** | `/dev/input/js*` 存在吗 | `gilrs` 打开的就是这个节点，**所以这是唯一说了算的判据** |
| **motor bus owner** | `fuser /dev/ttyS2` | **"端口存在"和"端口能用"是两个问题，只有第二个重要**。有人占着 → 每个舵机都会看起来不存在 |
| **kernel console** | `/proc/cmdline` + 启动配置文件 | **分三种状态**，见下 |
| **ONNX Runtime** | 解析符号链接，**打印版本号** | 只打印"存在"是不够的：**不兼容的运行时和正确的运行时，在 `robotd` 试着加载策略之前完全无法区分** |
| **failed units** | `systemctl list-units --state=failed` | 存在理由是个真实故事：`systemd-networkd-wait-online` 在这块板子上**每次开机都失败、持续了一周**，每次多花 20 秒、还把 `updaterd` 挡在 `network-online.target` 后面 —— **而没有任何东西报告它** |
| **wifi** | `nmcli` + `wlan0` 状态 | 四态：没有 `nmcli` / 没有 `wlan0` / NM 但没接管 / 已连接 |
| **networkd wait-online** | 是否 masked | 没 mask → "等着开机卡顿吧" |
| **clock** | `NTPSynchronized` | 无 RTC 的板子读 1970 → TLS 证书校验失败 → **在安装进行到好几步之后，以"看不懂的握手错误"形式暴露出来** |

**"kernel console" 那一项要单独讲 —— 它区分三种状态，因为这里有个时间差**：

> `/proc/cmdline` 是**正在运行**的那个内核；启动配置文件里改的是**下次启动**的那个内核。**这两者在重启前不可能一致。**

所以如果只打印一句"还在串口上"，在**刚刚修好这一项的那一次运行**里，会被读成"**修了没生效**"，白白多跑一趟。脚本的处理是：

| 情况 | 打印 |
| --- | --- |
| 已写 `console=display`，且本次有待重启的改动 | `${tty}，直到重启为止` —— **不警告**，已处理 |
| 已写 `console=display`，但没有待重启的改动 | `${tty} — CONFLICT` + 警告"这条线之外有别的东西在赢"（比如 `extraargs=`、或 U-Boot 里烧死的 `bootargs`）—— **并且明确说"再改一遍 `console=` 也没用"** |
| 没写 `console=display` | 警告"脚本**故意**没动它 —— 它只重写 `console=both` 和 `console=serial`" |

**最后的分支**：`needs_reboot=1` 就打印"该重启了 + 重启后怎么继续"（按 `persisted` 分两种命令）；否则打印"**板子就绪 —— 下一步装守护进程**" + `install.sh` 的获取命令（按有没有 token 分两种形式，**token 依然只打变量名**）。

#### 6.6.3 记住这个反复出现的"主角"：静默失败

整份脚本里，**最危险的一类失败出现了四次，全都长一个样**：

> **板子正常启动、不报错、`dmesg` 也不说，只是设备不存在。**

| 出问题的地方 | 静默的原因 |
| --- | --- |
| `overlay_prefix=rk35xx` 而文件叫 `rk3568-*` | 加载器找不到，什么都不说 |
| 摄像头 dtbo 没有 `rk3568-` 前缀 | 同上 |
| `overlays=` 里写了一个磁盘上不存在的名字 | 启动时跳过，什么都不说 |
| 内核 console 偶尔往舵机总线写日志 | 大部分时间安静 → 表现成"没有规律的间歇性故障" |

**这就是为什么这活儿必须是"脚本"而不是"一份操作清单"** —— 清单没法替你检查"我刚才那一下到底生效了没有"。**设计任何 bring-up，都要专门为"静默失败"设计一个可观察的判据。**

### 6.7 【方法论】换一块新板子 / 换个新机器人，怎么自己设计 bring-up

> 这一节把上面那份脚本**抽象成方法**。下次硬件换了，照这 8 步走，你能自己写出对应的 bring-up 流程。

#### 第 1 步：列出"这台机器人需要哪些设备节点"

**不要从"要装什么软件"开始，从"软件要打开哪些 `/dev/*` 开始"。** Microduck 的清单是：

| 设备 | 节点 | 谁用 |
| --- | --- | --- |
| 舵机总线 | `/dev/ttyS2` | `robotd`（15 个舵机） |
| 机身 IMU | `/dev/i2c-imu`（i2c4，0x6A） | `robotd` |
| 音频 codec + 头部 ToF | `/dev/i2c-pihat`（i2c3，0x18 / 0x29） | `mediad` / `tofd` |
| 摄像头 | `/dev/video*` | `mediad` |
| 手柄 | `/dev/input/js*` | `padd` |

**这一步的产出 = 一张"节点清单"。** 后面每一步都是为了让这张清单变成现实。

#### 第 2 步：每个节点，问三个问题

| 问题 | 怎么查 | 为什么问 |
| --- | --- | --- |
| 它挂在哪个 **SoC 控制器**上？ | SoC 数据手册 + 板子原理图（引脚复用表） | 这决定了要开哪个 overlay |
| 它的 **设备树地址**是什么？ | 内核源码/设备树里的 `fe5c0000.i2c` 这类地址 | 这是给它做**稳定别名**时唯一靠得住的锚点 |
| 它的 **设备地址/ID** 是什么？ | I²C 是 7 位地址（如 `0x6A`）；串口设备是总线 ID | 后面 `i2cdetect` 要靠它判断"到没到" |

#### 第 3 步：确认设备树默认开没开

```bash
ls /dev/ttyS* /dev/i2c-* /dev/video*     # 节点在不在
dmesg | grep -iE 'ttyS|i2c|video'        # 内核探测到没有
cat /proc/device-tree/model; echo        # 确认自己是什么板子
```

**没开 → 要找/写 overlay**。找的顺序：

1. 镜像**自带**的 overlay 目录里有没有现成的（Armbian：`/boot/dtb-<ver>/rockchip/overlay`；Radxa OS：`/boot/dtbo/`）；
2. 厂商文档 / 板子论坛；
3. 都不行 → 自己写 `.dts`，用 `dtc -@ -I dts -O dtb -o out.dtbo src.dts` **编译**（**`-@` 是必须的**，它保留符号信息，否则 overlay 没法"嫁接"到基树节点上）。

**装 overlay 时最容易踩的三个"静默失败"**（§6.6.3）：
- **前缀要对**（`overlay_prefix` 要和文件名前缀一致）；
- **文件名要有前缀**（没有就复制一份加上）；
- **`overlays=` 里的每个词，磁盘上都必须真的有对应文件**。

#### 第 4 步：确认没有"别人"占着这个控制器

**这是最容易被完全跳过、又最难查的一步。**

| 占座者 | 怎么发现 | 怎么赶 |
| --- | --- | --- |
| 登录终端（`serial-getty@ttyX`） | `systemctl is-enabled serial-getty@ttyS2`；`fuser -v /dev/ttyS2` | **mask**（不是 disable），因为 `getty.target` 会把它拉回来 |
| 内核 console | `cat /proc/cmdline` 里有没有 `console=ttyS*` | 改成屏幕（Armbian：`console=display`；Radxa OS：`extlinux.conf` 里 `console=tty1` 并删 `earlycon`）。**改完必须重启** |
| 其它驱动 | `fuser -v /dev/<节点>` | 按驱动本身的方式关掉 |

> **判据永远用 `fuser`，不要靠"我觉得没人用"。** 脚本里那句话值得抄下来：**"端口存在"和"端口能用"是两个问题，只有第二个重要。**

#### 第 5 步：给会变号的设备名做稳定别名

`/dev/i2c-N` 这种编号是枚举出来的，**会变**。用 udev 按**设备树地址**起别名：

```
SUBSYSTEM=="i2c-dev", KERNELS=="fe5d0000.i2c", SYMLINK+="i2c-imu"
```

规则放进 `/etc/udev/rules.d/`，**一个设备一个文件**（互不覆盖）。写完立刻应用：

```bash
sudo udevadm control --reload-rules
sudo udevadm trigger --subsystem-match=i2c-dev
```

**这样已经插着的设备不用重启就生效。**

#### 第 6 步：找出"运行时加载的依赖"，单独装

问一句：**我的程序在运行时 `dlopen` 了什么？**

| 类型 | 例子 | 特点 |
| --- | --- | --- |
| **编译期链接进去的** | Cargo 静态链接的 Rust 代码 | 跟 release 一起走，不用管 |
| **运行时加载的** | ONNX Runtime（`.so`） | **必须单独装**，而且**要检查版本、不只是存在性** |

**为什么单独装**：它比软件变得慢，塞进每个 release 是浪费。**代价是"能装上、能启动，然后功能不可用"** —— 所以第 7 步的 report 必须把它列为一项。

#### 第 7 步：写一个 `report`，把"准备好了吗"变成一条命令

**这是整套方法里回报最高的一步。**它要满足四个条件：

1. **只读**（随时能跑，不改任何东西）；
2. **不管有没有改动都打印**（"现在怎么样"本身是个值得问的问题）；
3. **打印"值"而不是"在不在"**（ONNX 要打印**版本**，因为不兼容的版本和正确的版本**在出事之前完全无法区分**）；
4. **每一项都说清"如果不是这样，去查什么"**。

**特别是**：凡是有"改完要重启才生效"的东西，**必须区分"正在运行的"和"下次启动的"**（`/proc/cmdline` vs 启动配置文件），否则你会在**刚修好的那一次运行**里以为没修好。

#### 第 8 步：给每一步标"硬 / 软"，决定失败时要不要停

| 等级 | 判据 | 处理 |
| --- | --- | --- |
| **硬**（`die`） | 不做这件事，机器人**完全不能动** | 立刻退出并说明 |
| **软**（`warn`） | 不做这件事，机器人**照样能走**，只是少个功能 | 警告后继续 |

Microduck 的划分是：**只有电机总线是硬的**；音频、摄像头、ToF、蓝牙全部是软的。

> **为什么这个划分值得较真**：bring-up 是**一次要跑十几步的长流程**。如果音频失败就整个中断，你会为了"鸭子叫声"卡住整个机器人 —— 而这两件事之间毫无关系。

#### 附：反面清单（自己写 bring-up 时不要做的事）

| 不要做 | 因为 |
| --- | --- |
| 直接写配置、不先检查 | 第二次跑会搞坏第一次的成果（不幂等） |
| 在脚本里自己重启 | 会切断 SSH，你失去排查窗口 |
| 把"改启动配置"和"装软件"揉成一个脚本 | 生命周期、频率、风险都不同 |
| 把高风险操作（改网络栈）混进"随便重跑没关系"的流程 | 它需要一次明确的、单独的决策 |
| 只判断"文件存在"就跳过 | 版本不兼容比不存在更难查（它会**启动成功然后 panic**） |
| 在报错里写死文件路径 | 脚本一旦被复制到别处，建议就与现实不符 |
| 把 token 的值打印出来 | bring-up 日志会被贴进聊天和 issue |

> **这一节的方法只针对"硬件 bring-up"。** 想拆**任何**脚本 / 工具（不止硬件，包括"别人让你照着敲"的任何东西），看 **§10.0 的七步法**。

---

## 7. 部署 microduck 软件栈（安装守护进程）

**整节在干吗**：把 §1 里说的那组 Rust 守护进程（`robotd`、`configd`、`btd`、`padd`、`mediad`、`updaterd`）装进板子，并让 systemd 开机自动拉起它们。做完这一步，板子才从"一台 Linux 小电脑"变成"一台机器人"。

**为什么必须做**：到现在为止板子只是个能上网的 Linux —— 舵机、IMU 都没人读，走路策略也没人跑。这一节装的就是"读舵机、跑 ONNX、走 50Hz 控制回路"的那套软件。

**这一节的核心特点（先理解，后面每一步都是它的推论）**：

| 特点 | 含义 | 你会看到什么 |
| --- | --- | --- |
| **一切都要签名验证** | 每个 release 都用 minisign 签名，板子上只认 baked-in 的公钥 | 签名不对 → 直接拒绝安装，不是"警告一下继续" |
| **引导靠"先下一个 updaterd"打破循环** | "更新需要更新器，而更新器本身要靠更新送过来"——解法是先单独下一个裸 `updaterd` 二进制，由它走**正常**安装引擎 | 安装日志里会看到 `fetching the bootstrap updaterd` |
| **装完会验一次哈希闭环** | 那个裸二进制是**未经签名**下载的；装完后脚本比对它的 sha256 和签名release 里的 `bin/updaterd` | 日志里 `bootstrap binary verified against the signed release` 就是这一步 |
| **绝不覆盖你的配置文件** | `/etc/robot/updater.toml`、`/etc/robot/robotd.toml` 装一次就不再动 | 重跑时看到 `keeping the existing ...` = 正常 |
| **幂等** | 重复跑安全；但如果已经装过 release，它会**跳过引导** | 会打印 `a release is already live (...); skipping the bootstrap` |

**本节完成标志**：`sudo sh ~/install.sh` 跑到最后打印出 `installed daemon <版本号>` + 一串 `robotctl ...` 提示，且 `systemctl is-active robotd updaterd` 都是 `active`。

### 7.0 【只读】先确认前置条件（省得跑到一半才炸）

> **在干吗**：`install.sh` 开头自己会检查这些，但提前看一眼，比等它报错快。

```bash
uname -m                                   # 期望 aarch64（脚本只发 aarch64 二进制）
id -u                                      # 现在是普通用户就行，脚本自己会要 root
command -v curl systemctl sha256sum install # 四个工具都要在（Debian 自带）
timedatectl show --property=NTPSynchronized --value   # 期望 yes
ls -l /dev/ttyS2                           # 期望存在，且没被 getty 占（§6 的验收）
```

**为什么要看时钟**：板子**没有电池 RTC**，开机时间可能是 1970。TLS 校验证书日期时会失败，而报错长得像"网络握手玄学失败"，极难往时钟上想。脚本里有一整段 `wait_for_clock`（最多等 2 分钟），就是为这个。**没同步 = 先解决网络（§5.1）再来。**

### 7.1 【动手】确认"要装哪个仓库的哪个版本"（三个环境变量）

> **在干吗**：这个脚本本身是**通用**的（官方默认指向 `pollen-robotics/microduck`）。你得告诉它：装**哪个仓库**的 release、从**哪个分支**拉脚本和密钥。这三个变量各管一段，不要混：

| 变量 | 管什么 | 默认值 | 你什么时候要设 |
| --- | --- | --- | --- |
| `DUCK_REPO` | **release 和密钥从哪个 GitHub 仓库来** | `pollen-robotics/microduck` | 用你的 fork / 私有仓库时必须设 |
| `DUCK_REF` | **脚本和公钥**从哪个 ref 读（不是配置、不是二进制） | `main` | 一般 `main`；要复现某次就别改 |
| `DUCK_TOKEN` | 私有仓库的读权限令牌；也用于下载 release 资产 | 空 | **仓库私有**时必设 |

> ⚠️ **`DUCK_REF` 故意不管配置文件**：脚本从 `main` 拿**公钥**（密钥集合只增不减，最新最安全），却从**正在装的那个 release 的 tag** 拿 `updater.toml`/`robotd.toml`（配置字段只有同版本的二进制才认识）。这不是笔误 —— 用 `main` 的配置喂给旧二进制会报 `unknown field 'allow_users'`，官方为此专门踩过一次。

**这条命令是私有的还是公开的？** —— `DUCK_REPO` 填错会有一个很迷惑的现象：

> **私有仓库忘了 token，GitHub 返回的是 `404` 而不是 `401`** —— 报错看起来像"网址写错了/仓库不存在"，而不是"你没权限"。所以一旦看到 `404`，先怀疑 token，别去改 URL。

### 7.2 【动手】设置环境变量（在板子上，SSH 会话里）

```bash
# ① 仓库：换成你实际要装的仓库（官方默认 pollen-robotics/microduck）
export DUCK_REPO=pollen-robotics/microduck

# ② 脚本/公钥的 ref
export DUCK_REF=main

# ③ 私有仓库才需要 token
export DUCK_TOKEN=github_pat_替换成你的token

# ④ 让这块板子成为"开发板"（信任 team.dev.pub，可装分支构建）
export DUCK_DEV_KEY=$HOME/team.dev.pub
```

**逐条在干吗**：

- **`DUCK_TOKEN` 从哪来**：GitHub → Settings → Developer settings → **Personal access tokens**，勾 **Contents: Read**（fine-grained）或经典 token 的 `repo`。**只给读权限**，别用全权限 token。
- **`DUCK_DEV_KEY` 是可选但建议**：它做两件事，**缺一不可**（脚本里写得很明确）—— ① 把 `team.dev.pub` 装到 `/etc/robot/trusted_keys/team.dev.pub`；② 把 `/etc/robot/updater.toml` 里的 `allow_dev_keys` 改成 `true`。**只做一件 = 板子依然拒绝分支构建，报错还长得像"release 损坏"。**
  - ⚠️ 这也是个**安全开关**：它让这块板子**无条件信任团队任何人推的分支构建（未经审查）**。所以官方刻意**不**把这个 key 放进仓库、也不自动下载 —— 必须是"这一块板子"的人工决定。**别对要出厂的机器人这么做。**
  - 撤销方法（脚本自己也会打印）：
    ```bash
    sudo rm /etc/robot/trusted_keys/team.dev.pub
    sudo sed -i 's/^allow_dev_keys.*/allow_dev_keys        = false/' /etc/robot/updater.toml
    sudo systemctl restart updaterd
    ```
- **`DUCK_DEV_KEY` 传的必须是公钥**：文件名 `team.dev.pub`，内容以 `untrusted comment:` 开头（minisign 格式）。传成私钥/签名文件的话，脚本会 `die`。

**完成标志**：`echo $DUCK_REPO $DUCK_REF` 有值；`ls -l ~/team.dev.pub` 文件在。

### 7.3 【动手】执行安装

> **在干吗**：跑 `install.sh` 的主流程。它按顺序做 11 件事（见下表），中途任何一步 `die` 都会立刻停 —— **这是好事**，说明它宁愿什么都不装，也不装半截。

```bash
sudo -E sh ~/install.sh
```

**为什么是 `sudo -E sh`、不是 `./install.sh`**：

- `sudo` —— 它要写 `/opt`、`/etc`、`/usr/local`、建系统用户、操作 systemd，全程 root；
- **`-E`** —— `sudo` 默认**清空环境变量**，不加 `-E` 的话你刚 export 的 `DUCK_TOKEN`/`DUCK_REPO`/`DUCK_DEV_KEY` **全部丢失**，脚本会安静地按官方默认仓库装（然后 404 或装错东西）；
- **`sh`（显式解释器）** —— 有些镜像的 `/tmp`、家目录挂 `noexec`，直接 `./install.sh` 会 `Permission denied`；用 `sh` 显式执行最稳。

**它会依次做这 11 步**（括号里是脚本里的函数名，看日志时能对上）：

| # | 步骤 | 在干吗 | 失败了会怎样 |
| --- | --- | --- | --- |
| 1 | `check_environment` | 必须是 root、必须是 aarch64、`curl/systemctl/sha256sum/install` 都要在、`REPO` 不能还是占位符 | `die` 退出（**最早失败，最省时间**） |
| 2 | `check_board` | 看 `/dev/ttyS2` 在不在、有没有 `serial-getty@ttyS2` 占着 | 只 **warn**，继续装（裸板也值得装，好测更新系统） |
| 3 | `wait_for_clock` | 等 NTP 同步（无 RTC，最久 2 分钟） | 超时只 warn，但后面 TLS 很可能失败 |
| 4 | `resolve_bootstrap_asset` | 问 GitHub API「最新稳定 release 是哪个 tag、里面的 `updaterd-bootstrap-aarch64` 资产 id 是多少」 | `die`（没有稳定 release 就没法引导） |
| 5 | `install_config` | 从 `main` 拉 3 个公钥；从 release tag 拉 `updater.toml`/`robotd.toml` —— **已存在则保留不覆盖** | 拉不到 `release-1.pub` → `die`（没它什么都验不了） |
| 6 | `install_dev_key` | 装 `team.dev.pub` + 打开 `allow_dev_keys`（仅当你设了 `DUCK_DEV_KEY`） | 文件格式不对 → `die` |
| 7 | `bootstrap_first_release` | 下裸 `updaterd` → 让它走正常引擎装第一个 release（**验签**）→ 比对 sha256 闭环 | `die`；**打印两个哈希**并让你当"下载被劫持"处理 |
| 8 | `create_group` | 建 `robot` 组 + `btd`/`padd` 系统账号，**并把你（`radxa`）加进 `robot` 组** | 建不出 `robot` 组 → `die`（两个服务都声明 `Group=robot`） |
| 9 | `install_units` | 从 release 里拷 systemd unit、装 journald 持久化 drop-in、把 `robotctl` 链到 `/usr/local/bin`、装 `robot-rescue`/`robot-boot-check`、`enable --now` 各服务 | 缺 `updaterd.service`/`robotd.service` → `die`；缺 `configd/btd/padd/mediad` 只 warn |
| 10 | `install_token_dropin` | 有 token 时写 `/etc/systemd/system/updaterd.service.d/token.conf`（**权限 600**）并重启 updaterd | 没 token 只提示"updaterd 拿不到更新" |
| 11 | `verify_install` + `report` | 检查必需文件、`is-active updaterd robotd`、跑 `robotctl version`/`health`，最后打印安装报告 | `updaterd`/`robotd` 起不来 → `die` |

> **第 8 步的副作用很重要**：脚本把你加进 `robot` 组后**会明确告诉你**：**当前这个 shell 还没生效**（进程的附属组在 `exec` 时就固定了，root 也没法改别的进程的组）。所以它会让你跑一条：
> ```bash
> newgrp robot
> ```
> **不跑会怎样**：`robotctl health` 报 `cannot reach robotd at /run/robotd.sock: Permission denied` —— **看起来像守护进程崩了，其实只是组没生效**。重新登录（或新开一个 SSH 会话）也一样有效。

**预期输出骨架**（对照着看，就知道跑到哪了）：

```
==> fetching the bootstrap updaterd
==> installing the first release (verifying signatures)
==> bootstrap binary verified against the signed release
==> keeping the existing /etc/robot/updater.toml        ← 只在重跑时出现
==> creating the robot group and the service accounts
==> added radxa to the robot group
==> installing systemd units
==> units from the release: updaterd.service robotd.service ...
==> verifying
  updaterd   active
  robotd     active
==> installed daemon 0.x.y
```

**完成标志**：最后一行是 `installed daemon <版本>`，并且 `updaterd`、`robotd` 都是 `active`。

**卡住了怎么办**：

| 现象 | 原因 | 修法 |
| --- | --- | --- |
| `error: run as root (pipe to \`sudo sh\`, not \`sh\`)` | 忘了 `sudo` | 加 `sudo -E` |
| `this installer publishes aarch64 binaries only` | 架构不对（装错镜像 / 在 x86 上跑） | 确认 `uname -m` = `aarch64` |
| `REPO is still the placeholder 'ORG/...'` | 没设 `DUCK_REPO` 而脚本里是占位符 | `export DUCK_REPO=你的仓库` |
| `cannot read .../releases/latest` | 仓库没发布过**稳定** release（只有 prerelease） | 让上游 promote 一个；用私有仓库则确认 token |
| 下载 404，但仓库明明存在 | **私有仓库没给 token**（GitHub 用 404 掩盖 401） | 设 `DUCK_TOKEN` 后重跑 |
| `the latest release has no asset named updaterd-bootstrap-aarch64` | release 里没带引导资产 | 是上游打包问题，不是你的板子 |
| 卡在 `waiting for the clock to sync` | 板子没网 / NTP 没通 | 先修 Wi-Fi（§5.1），再重跑 |
| `the bootstrap binary does not match bin/updaterd` | 引导二进制与签名 release 不一致 | **按提示当成"下载被篡改"排查**，别重试掩盖 |
| `robotctl` 报 `Permission denied (os error 13)` | `robot` 组还没生效 | 跑 `newgrp robot`，或重开 SSH 会话 |
| 重跑脚本后版本号没变 | **已装 release 时脚本会跳过引导** | 这是设计：装完的板子要靠 `sudo robotctl update apply daemon` 升级 |
| `btd did not start` / `padd did not start` / `mediad did not start` | 这三个是**允许失败**的（蓝牙要 73 秒才出现 `hci0`；`padd` 要手柄；`mediad` 要 GStreamer 栈） | 机器人照样能更新、能走路，只少了对应功能；查 `journalctl -u btd -b` |
| `the release carries no scripts/robot-rescue` 之类 | 从**分支**装、而 release 是更早的稳定版 | 无害；下次更新会带上 |

> ⚠️ **重跑 `install.sh` 不会升级已装的机器人**。脚本只负责"从零引导一块裸板"；装过之后它会打印：
> ```
> a release is already live (releases/0.x.y); skipping the bootstrap
> ```
> 想更新走 §9.5。想让新版**强制重装**（比如已装的 `updaterd` 太旧、把新版回滚了），才用 `DUCK_FORCE_REINSTALL=1` —— 注意它**会先停掉所有守护进程**，且**这次安装没有健康门、不能自动回滚**。

### 7.4 【动手】装完必须重启一次（重要）

```bash
sudo reboot
```

**为什么必须重启**：release 自带的 `hooks/postinstall` 在脚本能插手之前，就把所有 unit `enable --now` 了一遍 —— 也就是说 **`btd` 已经跑过一次**。而守护进程**不会撤销它已经推给子系统的状态**（`btd` 死了也会留下 `Pairable=1`、一个广播实例、配对代理给适配器开的 IO 能力）。**只有重启才能把这些状态清干净**，第一次开机才是"诚实"的。

**为什么这一步和 §0.7 强绑定**：重启是**唯一的失联风险点**。重启前必须已经做过 §0.7 的 Wi-Fi 自动连修复（`psk-flags=0`），否则重启后板子不联网，SSH 再也进不来。

### 7.5 一条命令完成上面全部（熟练后用）

> **在干吗**：`provision-board.sh` 是**在你 Windows 主机上**跑的编排脚本：它把 `setup-board.sh` + `install.sh`（还有 GStreamer、rkaiq 等可选栈）打包送到板子、远程执行、再给机器人起个名字。**和手工的唯一区别是"谁在敲命令"**，走的流程完全一样。

```powershell
cd E:\optiDuck\joyandai\microduck
$env:DUCK_TOKEN="github_pat_替换成你的token"
./scripts/provision-board.sh --pause-btd-on-pair --name MY_DUCK radxa@<板子IP>
```

| 参数 | 干吗 | 你什么时候要加 |
| --- | --- | --- |
| `--pause-btd-on-pair` | 配对时暂停 `btd`，让手柄能正常 bond | **手柄配不上时**加（先试这个，比 `--weird-ble` 保守） |
| `--name MY_DUCK` | 给机器人起名（蓝牙广播名、`duckctl` 用它找板子） | 想要个好记的名字就加 |
| `--weird-ble` | 更激进的蓝牙兼容处理（改 `Privacy=device` 等） | **别乱开**，先试 `--pause-btd-on-pair` |
| `--no-gstreamer` / `--no-rkaiq` | 跳过摄像头/ISP 栈 | 没摄像头、想省时间 |

**第一次建议还是照 §7.1~7.4 手工走一遍** —— 出问题时你能看到每一步的输出，知道断在哪。摸熟了再用这条。

---

## 8. 验证部署是否成功

**整节在干吗**：装完不等于装对。这一节用**四层证据**从浅到深确认：有没有跑起来 → 是不是健康 → 是不是"开发板" → 控制回路在不在转。

**为什么按这个顺序**：`systemctl is-active` 只能告诉你"进程活着"，告诉不了你"它是不是真的能看到舵机"。§1 里强调过：`robotd` 在**没有舵机总线**时会**照常 `active`**、照常提供 socket、然后诚实地上报 `unhealthy` —— 所以"active"和"能干活的"是两回事，要分开验。

### 8.1 【只读】它到底在跑什么版本

```bash
robotctl version
```

**在干吗**：同时打印**正在运行**的版本和**磁盘上已安装**的版本。

**为什么第一件事永远是看版本**：后面所有排障都建立在"我知道跑的是哪份代码"之上。版本对不上（比如你以为装了新版、其实还跑着回滚后的旧版）会让你在完全错误的方向上找半天。

**完成标志**：能同时看到 running / installed 两个版本号。

### 8.2 【只读】健康报告（最重要的一条）

```bash
robotctl health
```

**在干吗**：一份软硬件体检 —— 电机总线、IMU、策略加载、时钟、控制回路实际频率、失败的服务单元等。

> ⚠️ **裸板报 `unhealthy` 是诚实的正确答案，不是安装失败。**
> 你现在的板子**还没接舵机**（或者舵机没上电）。`robotd` 打不开电机总线时会：记一条日志 → 继续提供 socket → 上报 `unhealthy`。脚本的 `verify_install` 对这一步**故意不判失败**（裸板是测更新系统的合法状态）。
> **接上舵机、给舵机供电后，`robotd` 会自己重试并好起来 —— 不用重装、不用重启服务。**

**完成标志**：无论 healthy 还是 unhealthy，**报告里指名道姓说出原因**（比如 `no robot on the motor bus`）—— 能说出原因就说明软件链路是通的。

### 8.3 【只读】确认它真的是"开发板"（能装分支构建的前提）

```bash
ls -l /etc/robot/trusted_keys/team.dev.pub          # 期望：文件存在
grep '^allow_dev_keys' /etc/robot/updater.toml      # 期望：allow_dev_keys        = true
```

**在干吗**：核对 §7.2 说的那"两半"是否都在位。

**为什么要两半都查**：只有 key 没有 `allow_dev_keys = true`（或反过来），板子**依然拒绝分支构建**，而报错长得像"release 签名损坏"，会让你去查错方向。

**完成标志**：文件在 + `= true`。两条缺一 → 重跑 `install.sh`（带上 `DUCK_DEV_KEY`）。

> 如果你是走 `provision-board.sh` 装的，它还会往 `/var/lib/robot/provision.log` 写一行，可以顺手 `grep -c 'DEV BOARD' /var/lib/robot/provision.log` 看（输出 `1` = 是）。手工跑 `install.sh` 时这个文件不存在，**以上面两条命令为准**。

### 8.4 【动手】`newgrp robot`（如果脚本提示了）

```bash
newgrp robot
```

**在干吗**：开一个**新的 shell**，让它带上 `robot` 组身份。

**为什么必须做**：socket 是 `0660 root:robot` —— 普通用户能连 `robotd` **完全靠这个组**。而进程的组集合在启动时就固定了，**没法给已存在的进程加组**（root 也不行）。所以脚本**不可能**把当前 shell 修好，只能让你 `newgrp` 一下（或者退出重登）。

**不做的症状**：`Permission denied (os error 13)` —— 看着像 daemon 崩了，其实只是没进组。

**完成标志**：`groups` 输出里出现 `robot`，且 `robotctl health` 不再报 permission denied。

### 8.5 【只读】实时看控制回路

```bash
robotctl monitor
```

**在干吗**：把 50Hz 控制回路的实时状态画在终端上 —— 意图 vs 实际、每个关节的角度、IMU 姿态、电池电压、当前策略名、摔倒判定，以及**底部边框上的实际达成频率**。

**为什么值得看**：`[control] hz = 50` 是**从树莓派 Zero 2W 的原型继承来的，从没在 Radxa 上重新推导过**（`robotd.toml` 里就是这么写的）。所以"实际跑出来是不是 50"要靠这里量，不能靠假设。

**裸板会看到**：类似 `no robot on the motor bus` 的提示 —— **正常**。

**完成标志**：接上机器人后，底部频率接近 50Hz，且各关节读数在动。

### 8.6 【动手】重启一次，确认 headless 真的成立（收官验收）

```bash
sudo reboot
```

等 90 秒，**不接显示器、不做任何登录**，直接在 Windows 上：

```powershell
ssh radxa@<板子IP>
ssh radxa@<板子IP> "systemctl is-active robotd updaterd && robotctl version"
```

**在干吗**：这是对前六节所有工作的**一次综合验收** —— 它同时验了：SD 卡能启动（§4）、Wi-Fi 自动连（§0.7）、SSH 免密（§5）、守护进程开机自启（§7.3）。

**完成标志**：SSH 直接进去，且 `active` + 版本号正常打印。**到这一步，显示器、键盘、鼠标就可以永久撤掉了。**

---

## 9. 调试：从浅到深

> **排查顺序原则（照这个顺序走，别跳）**：**版本**（是不是旧代码）→ **服务状态**（进程在不在）→ **日志**（它自己怎么说）→ **硬件设备节点**（东西在不在、谁占着）。**别一上来就怀疑硬件。**

### 9.1 服务状态一网打尽

```bash
systemctl status robotd updaterd configd btd padd mediad tofd
```

**在干吗**：一次性看七个服务的状态 + 最近几行日志。

**怎么读**：`active (running)` = 活着；`failed` = 起不来（去看日志）；**`inactive (dead)` 且 `enabled` = 被停掉了**（不是崩溃）。

### 9.2 看日志（日志都进 journald）

```bash
journalctl -u robotd -b --no-pager | tail -40   # robotd 本次开机的日志
journalctl -u updaterd -f                        # 实时跟随 updaterd（Ctrl+C 退出）
journalctl -b -u robotd -u updaterd -u btd -u configd   # 全部核心服务一起看
```

- `-u 服务名` 只看某个服务；`-b` 只看**本次开机**；`-b -1` 看**上一次**开机（排查"上次开机就坏了"很有用）；
- ⚠️ **每条服务的第一行日志是"身份行"**（版本、git revision、exe 路径、pid），**任何日志级别都保留**。**先找这一行** —— 它一眼告诉你跑的是哪份代码、二进制在哪。

**为什么日志能活过重启**：这套系统的 `/var/log` 在部分镜像上是**内存（tmpfs）**，断电即失。所以 `install.sh` 会装一个 journald drop-in（`/etc/systemd/journald.conf.d/10-robot.conf`）让日志落盘。**"板上日志找不到了"** 就是没这个 drop-in 时的经典症状。

### 9.3 硬件设备节点体检

```bash
ls -l /dev/ttyS2 /dev/i2c-imu /dev/i2c-pihat   # 三个关键设备在不在
sudo i2cdetect -y 4                             # 机身 IMU：期望看到 0x6A
sudo i2cdetect -y -r 3                          # codec/ToF 所在总线：期望 0x18 / 0x29
fuser -v /dev/ttyS2                             # 谁占着舵机串口（有 agetty 就是 §6.1⑦ 的坑）
dmesg | grep -iE 'ttyS|serial'                  # 内核启动时串口/设备树相关线索
```

**关键判据**：

| 输出 | 意味着 |
| --- | --- |
| `/dev/ttyS2` 不存在 | overlay 没生效 → 回 §6 |
| `fuser` 显示 `agetty` 占着 | 登录终端在吃舵机回复 → mask `serial-getty@ttyS2` |
| `i2cdetect -y 4` 看不到 `0x6A` | IMU 总线/地址不对 → 查 §6 的 i2c4 overlay |
| `i2cdetect -y -r 3` 看不到 `0x18`/`0x29` | 音频/ToF 总线没开（**不影响走路**） |

### 9.4 板级脚本自带体检

```bash
sudo /usr/local/sbin/robot-setup-board
```

**在干吗**：重跑板级配置脚本（幂等，安全）。注意它在 §6.4 里把**自己复制**到了这个路径，所以 `/tmp` 被清掉也还在。

**看什么**：末尾的 **board status** —— 电机总线、蓝牙配对配置、手柄、内核 console、ONNX Runtime 版本、失败的服务单元、Wi-Fi 归属、时钟同步。**这是"哪一块还没配好"最快的答案。**

### 9.5 更新器排障

```bash
robotctl update status               # 各组件当前状态（谁在等、谁已就绪）
robotctl update check                # 有没有更新的 release
robotctl update log                  # 每次更新的历史（持久记录，断电不丢）
robotctl update show 42              # 第 42 次更新的完整过程 + 对应日志
sudo robotctl update apply daemon    # 手动触发更新（mutations 只有 root 能做）
sudo robotctl update rollback daemon # 手动回滚到上一个版本
ls -l /opt/robot/daemon/releases/ /opt/robot/daemon/current   # 装了哪些版本、current 指向谁
```

**在干吗**：这套更新系统是「**整目录替换 + 验签 + 健康门 + 自动回滚**」，不是打补丁。

**为什么必须知道 `update log`**：`/var/log` 可能断电即失，**`robotctl update log` 才是持久的更新历史**。板子出问题、又说不清什么时候变的，从这里翻。

**为什么更新会自动回滚**：装完新 release 后有一段观察期，如果健康门（`[update_gate]` 里的阈值）判定它不健康，系统会**自己滚回上一个版本**。所以"更新后好像没生效"有时是回滚了 —— `update log` 里能看到原因。

> ⚠️ **一个反直觉但很重要的事实**：健康门只回滚 **unhealthy**，**不回滚 `degraded`**。
> "看不到舵机"是 degraded —— 它在更新之前就是这么报的，回滚**修不好它**。**回滚只对"这次更新引入的问题"有意义**（§10.5）。

### 9.6 【动手】两条救命路径（板子起不来时）

```bash
sudo robot-boot-check      # 手动跑一次开机自检
sudo robot-rescue          # 把 release 退回"golden"（出厂那个已知好的版本）
```

**在干吗**：`install.sh` 会把这两个脚本装到 `/usr/local/sbin`（**是复制不是软链** —— 因为它们存在的意义就是"当 release 起不来时救它"，不能通过 `current` 去读，否则救援要经过被救援的东西）。

**另外还有一个 **开机自动兜底**：`robot-boot-check.timer` 在**每次开机 3 分钟后**问一句"这个 release 把自己的守护进程带起来了吗"，没带起来就回退到 golden。**这就是"装坏了会自己滚回去"的实现。**

> **这条链的完整设计（为什么是"死线"而不是 `OnFailure=`、180 秒怎么来的、`robot-rescue` 为什么什么都不解析）在 §10.6。**

---

## 10. 拆箱总纲：这份教程里还有哪些"黑箱"，以及怎么自己拆

**这一节在干吗**：§6.6 把 `setup-board.sh` 拆开了。但整份教程里，"照抄能跑、出了事说不清"的地方还有十几处 —— 这一节把它们**一次列全**，并且给出**一套通用的拆箱方法**，让你下次遇到任何没见过的脚本 / 命令 / 工具，都能自己拆。

**为什么值得花时间**：你的目标本来就是 —— **过一遍之后，下次换一块新板子、换一套新软件栈，自己能设计出流程**。而"能自己设计"的前提，不是记住 12 个函数，而是**掌握一套遇到黑箱就知道从哪下手的顺序**。

---

### 10.0 【方法论】拆任何一个黑箱的七步法

> 这一套跟硬件无关、跟 microduck 也无关。任何脚本、任何 CLI 工具、任何"别人让你照着敲"的东西，都这么拆。

| 步 | 做什么 | 为什么是这一步 |
| --- | --- | --- |
| **1** | **先读文件最上面那段注释，不要先读代码** | 写得好的脚本，文件头就是它的设计文档：为什么存在、故意不做什么、谁调用它。代码回答"**怎么做的**"，注释回答"**为什么这么做**" —— 你缺的是后者 |
| **2** | **找入口**（`main` / 最后几行 / `case` 分支），**把调用顺序抄下来** | **顺序本身就是信息**：为什么 X 必须在 Y 前面？这类排序约束通常就是整份脚本真正的知识点 |
| **3** | **每一步问四问**：在干吗 / 为什么必须 / 完成的标志 / 失败了怎么办 | 就是本教程每一节的格式。**四问答不全的地方，就是你还没懂的地方** |
| **4** | **专门找"静默失败"**（§6.6.3） | 最贵的一类 bug：**不报错、但没生效**。任何"改了配置"的动作，都要配一个"读回来验证"的动作 |
| **5** | **找它"故意不做"的事** | 成熟脚本里，"不做"和"做"一样是设计。**故意不重启、故意不覆盖配置、故意不装某个组件** —— 这些恰恰是最容易被你"顺手改一下"破坏掉的地方 |
| **6** | **找"生命周期 / 自我退休"的声明** | 它是**一次性的**还是**每次更新都跑**？它会不会**把自己卸载掉**？搞错了，你要么在错误的时间期待它，要么让两套机制互相打架 |
| **7** | **给每一步标"硬 / 软"**（§6.7 第 8 步） | 失败时是"必须停"还是"警告继续"，决定了你排障时的优先级 |

**这七步的产出是一张表**：

```text
步骤 | 在干吗 | 硬/软 | 成功的判据 | 静默失败会藏在哪
```

有这张表，你就不是在"用脚本"，而是在"用一套你理解的流程"。**这张表你搬到下一个项目也照样管用。**

**反面清单（拆箱时不要做的事）**：

| 不要做 | 因为 |
| --- | --- |
| 一上来就读代码细节 | 你会被一堆 `sed` 表达式淹没，却仍然不知道这个脚本为什么要存在 |
| 只看"成功路径" | 脚本一半的价值在失败处理上 |
| 看到 `--force` / `--bootstrap` 就直接用 | 逃生舱口的名字翻译过来就是"**我知道我在绕过什么**" |
| 看到"故意不做"的地方就顺手补上 | 那通常是踩过坑之后**特意**留下的空位 |

---

### 10.1 黑箱清单：这份教程里还有哪些没拆的盒子

| # | 黑箱 | 用在哪一节 | 黑在哪 | 拆解在 |
| --- | --- | --- | --- | --- |
| 1 | `migrate-network.sh` | §6.5 | 为什么网络要从 netplan 搬到 NetworkManager？"90 秒兜底"到底是什么 | §10.2 |
| 2 | `install.sh` 的信任链 | §7.3 | "先下一个没签名的二进制"凭什么不是后门 | §10.3 |
| 3 | `robotctl` 的权限模型 | §8 / §9.5 | 为什么有的命令要 `sudo`、有的不要 | §10.4 |
| 4 | 更新器本体（`updater.toml`） | §7.5 / §9.5 | "装坏了会自己滚回去"具体靠什么、在什么条件下**不**回滚 | §10.5 |
| 5 | `robot-boot-check` + `robot-rescue` | §9.6 | "永不变砖"到底怎么保证的 | §10.6 |
| 6 | `provision-board.sh` / `provision.sh` | §7.5 | 一条命令背后的三层协作 + 为什么它总要重启一次 | §10.7 |
| 7 | `dev-push.sh` | §12 | 一次推送在板子上**真正**发生了什么 | §10.8 |
| 8 | `/etc/robot/*.toml` | §7 / §12 | 哪个该改、哪个改了会被永久冻住 | §10.9 |
| 9 | 教程里没出现的那些脚本 | —— | 它们是什么角色，要不要管 | §10.10 |

---

### 10.2 `migrate-network.sh` —— 为什么网络要单独一个脚本

**它在干吗**：把板子的网络管理从 **netplan** 切成 **NetworkManager（NM）**，并且在切失败时**自己退回去**。

**为什么不能揉进 `setup-board.sh` 一起跑**（这是它单独存在的全部理由）：

| 理由 | 说明 |
| --- | --- |
| **生命周期不同** | 板级设备配置（overlay、舵机总线、音频）**一次配好、长期不变**；网络迁移**只该发生一次**，之后这条路径就该消失 |
| **风险等级不同** | 设备配错了 = 某个功能没有；**网络配错了 = 你再也 SSH 不上去**。高风险操作必须是一次**显式的、单独的**决策 |

**为什么必须是 NetworkManager，而不是继续用 netplan**（这段推理值得记住）：

1. **netplan 不是网络管理器，是"配置生成器"** —— 它把 YAML 翻译成后端（NM 或 systemd-networkd）的配置，**自己不提供扫描 API**；
2. **`netplan apply` 不报告"有没有连上"** —— 它只报告"配置是否成功下发"。**关联成功是异步事件，netplan 不管、也不说。** 这就是典型的静默失败：你以为连上了，实际在等一个永远不会来的 DHCP 应答。

**"90 秒兜底"（backstop）是整份脚本最值得看的一段**：

```text
apply 之后，最多等 90 秒，等 wlan0 拿到 IPv4 地址
  ├─ 拿到了  → 把兜底机制"退休"掉（删掉自己）
  └─ 没拿到  → 1) 把 /etc/netplan/*.yaml.disabled 改回 .yaml（还原）
               2) 写 [keyfile] unmanaged-devices=*（让 NM 别碰网卡）
               3) netplan generate（按老配置重新生成）
               4) 把自己禁用掉
               5) reboot  ← 回到"迁移之前"的状态
```

**你要带走的两条**：

1. **任何"改网络"的操作，都必须自带一条"走不通就回到原状"的路**，而且这条路**不能依赖网络** —— 否则你就在用它要修的东西修它自己；
2. **兜底机制要会自我退休**（`retire_net_check()` 会把 `/usr/local/sbin/robot-net-check` 和它的 unit 一起删掉）。**一个永远在跑的"临时兜底"，迟早会变成下一次故障的原因。**

---

### 10.3 `install.sh` 的信任链 —— 怎么解决"先有鸡还是先有蛋"

**它面对的死循环**：**更新需要更新器，而更新器本身要靠更新才能送上来。**

**解法（四步信任链）**：

| 步 | 做什么 | 为什么这样做不开后门 |
| --- | --- | --- |
| 1 | 从 `raw.githubusercontent` 取**两样东西**：一份配置 + 一组公钥 | 只有这两样是**必须**在"验证能力存在之前"拿到的 —— 它们本身就是**用来开始验证的**（公钥是信任锚点，不再是"要相信的内容"） |
| 2 | 单独下一个**裸 `updaterd` 二进制** | 它是**未经签名**的。这是整条链上**唯一**的裸下载 |
| 3 | 让这个裸 `updaterd` 走**正常**安装引擎去装签名 release | 关键：**引导二进制只负责"启动引擎"，安装过程本身仍然要验签** |
| 4 | **装完做一次 sha256 闭环比对**：裸二进制的哈希 == 签名 release 里 `bin/updaterd` 的哈希 | 用第 3 步的结果**反过来证明**第 2 步那个裸下载没被调包。**闭环一合上，裸下载就被"追认"了** |

**几个你会在日志里看到、但不知道什么意思的短语**：

| 日志里的字样 | 意思 |
| --- | --- |
| `fetching the bootstrap updaterd` | 第 2 步：正在下那个裸二进制 |
| `bootstrap binary verified against the signed release` | 第 4 步：哈希闭环**合上了**，整条链成立 |
| `bootstrap binary does not match` | 闭环**没合上** → **按"下载被篡改"处理，不要重试掩盖** |
| `a release is already live (...); skipping the bootstrap` | 板子上已经有 release 了 → 跳过引导。**这也是"重跑 `install.sh` 不会升级"的原因** |

**还有一条设计声明值得单独记**（文件头原话）：**"这个脚本从不解析 manifest"**。

> 意思是：`install.sh` 自己**不做**"读清单决定装什么"这种事 —— 那是 `updaterd` 的工作。**它只负责"把引擎送上板子并让它跑起来"。** 看清这句话，你就知道这个脚本的边界在哪，也就不会指望它去干更新的活。

**三个 ref 变量为什么是分开的**（`ENV_REF` / `REF` / `CONFIG_REF`）：脚本和公钥从**你指定的 ref** 取；**配置默认跟着 release 的 tag 走**。分开是为了**修一个真实事故**：曾经配置跟着主分支走，于是主分支上任何一次配置改动，都会**立刻作用到所有板子上** —— 那等于**绕过发布流程改线上**。**配置也是代码，也得走版本。**

---

### 10.4 `robotctl` 的权限模型 —— 为什么有的要 `sudo`、有的不要

**它的通信方式**：`robotctl` 只是一个 **CLI 客户端**，通过 unix socket 和板子上的守护进程说话。socket 是 `/run/robotd.sock`，权限 **`0660 root:robot`**。

**全部行为都由这一行推出来**：

| 现象 | 原因 |
| --- | --- |
| 你得在 `robot` 组里，才能跑 `robotctl` | `0660` + 组 = **"能不能连上"**这一层 |
| **只读命令永远不需要额外授权**（`status` / `log` / `check` / `listInstalled` / `subscribe`） | 设计原话：**"能连上 socket 已经要求了组权限了；而支持人员必须能检查一台他无权改动的机器人。"** |
| **改动命令**（`update apply` / `rollback` / `select` / `pin`）要 root，或列在 `allow_users` 里 | 这是**第二层**授权，和"能不能连上"是两件事 |
| 明明进了组，还是报 `Permission denied (os error 13)` | 组没在**当前 shell** 生效（§8.4） |

**这里有一条"永远不要改"的红线**（`updater.toml` 里有注释，还有测试盯着）：

> **`allow_groups = ["robot"]` 绝对不能出现。**
> 在 `robot` 组里 = 有资格**和 updaterd 说话**；如果把"说话"和"改固件"合成一层，**任何能看状态的人就都能换固件**。**两层必须是两层。**

**为什么 `allow_users` 里只写 `btd`**：因为"用手机 App 更新机器人"这条路上，请求是 `btd`（蓝牙守护进程）**转达**的。注意它授权的措辞有多窄 —— **"`btd` 可以转达一条来自 App 的更新请求"，而不是"robot 组里的任何东西都能换固件"**。

而且**按名字、不按 uid**：systemd-sysusers 是**动态分配 uid** 的，写死一个数字，在这块板子上对、在下一块上就错。

---

### 10.5 更新器本体 —— `updater.toml` 里的每一个"故意"

**这一小节解决你的核心疑问**："装坏了会自己滚回去"，靠什么成立、什么时候**不**成立。

**先看懂磁盘布局，其余都好懂**：

```text
/opt/robot/daemon/
├── releases/<版本号>/     ← 每个版本一个完整目录（整目录替换，不是打补丁）
├── current                ← 软链，指向"现在在跑的"
└── golden                 ← 软链，指向"永不删除的已知好版本"（1.0.0 之前故意不设）

/var/lib/robot/updater/    ← 状态目录：更新历史、救援面包屑
```

**原则一**：`state_dir` **故意放在所有 `install_dir` 之外**。

> 因为它是"**记录这次替换发生了什么的簿子**"，而替换 / 回滚会波及 `releases/` 里的东西 —— **簿子不能跟着一起被换掉**。（对应 §6.6 的第 1 条原则：**别把信息和承载它的东西放在同一个生命周期里。**）

**原则二**：健康门只回滚 **unhealthy**，不回滚 **degraded**。

| 判定 | 例子 | 更新器怎么办 |
| --- | --- | --- |
| **unhealthy** | 控制回路起不来、socket 不响应 | **回滚** |
| **degraded** | "看不到舵机"（裸板没接舵机） | **不回滚**，健康门放行 |

**为什么 degraded 不回滚**：**它在替换之前就是这么报的** —— 回滚**修不好它**，只会把**历史上每一个 release 都回滚掉**。**回滚只对"这次更新引入的问题"有意义。**

**原则三**：`on_apply.units` 里有两个**故意的缺席** —— `updaterd` 和 `btd`。

> **规则：一个服务不能被"它自己正在执行的那个操作"重启。**
> - `updaterd`：它是**执行更新的那个进程** —— 重启它 = 更新执行到一半自杀；
> - `btd`：它可能就是**发起更新的那条传输通道** —— 重启它 = 手机上的进度流断掉，**发起更新的人永远等不到结果**。
>
> 两个都**不等重启**：更新回复后 5 秒重启它们；并且**下一次 `updaterd` 启动时会检查这次重启有没有发生，没发生的补上**。

**原则四（一段值得记住的 bug 史）**：`units` 列表是 **"additive, not authoritative"（只做补充，不是权威清单）**。

- 真正要重启哪些，是**从 release 实际带的 unit 推导**出来的；
- 这份列表**只需要写 release 没带的那些** —— 所以 `["robotd", "configd"]` 两个其实**都是多余的**，留着是因为"写出来的配置比一个空列表更好读"；
- **它以前是权威的，那就是这个 bug**：这个文件属于**运维**、且 `install.sh` 会**保护**它，于是**在 `configd` 出现之前就布好的板子，会永远留着 `units = ["robotd"]`** —— 结果每次更新都换了 `configd` 的二进制，**却一直跑着老进程**。

> **你要带走的那一条**：**"配置文件里写死一份清单"这种做法，迟早会和现实脱节，而且脱节时一声不响。** 能推导的就推导，配置里只写"推导不出来的部分"。

**其余关键值（速查）**：

| 键 | 值 | 为什么 |
| --- | --- | --- |
| `trusted_keys_dir` | `/etc/robot/trusted_keys` | 三个 release 公钥**一次全装进去**（虽然现在只有 `release-1` 在签）—— 板子只能认它出厂时烧进去的那组钥匙，**这是"将来能换钥匙"的唯一机会**，否则得重新刷机 |
| `check_interval` | `6h` | 没有轮询，"最低支持版本"就形同虚设：板子**只会在有人打开 App 时**才知道自己被淘汰了 |
| `auto_apply` | `mandatory` | 只自动装**带 `min_supported` 的** release（= 我们已经撤回的坏版本）；**普通版本仍然等用户点** —— 机器人什么时候重启是主人的决定 |
| `golden` | 故意**不设** | 它必须指向一个**真的装过**的版本。设一个从没装过的号，会让救命命令在**最需要它的那一刻**失败 —— 还不如诚实地说"没配 golden" |
| `keep_previous` | `1` | 保留上一个版本，才有"回滚"这个动作 |
| `health.probe` / `timeout` | `socket` / `30s` | 健康门的判据是**真测量**（socket 能不能应答），不是"进程还在" |

**最后一个"故意"**：`[component.models]` 整段**不在这份文件里**，而且注释明说"**这不是疏漏，别照抄示例补上**"。

> 理由：示例里配的模型仓库**现在根本不存在**。一个 404 的组件会让**每一次 `check` 都报一次失败** —— 结果是**读机器人状态的人学会了忽略失败**。
> **每多一个"习惯性失败"，真正的失败就少一分被看见的机会。**

---

### 10.6 永不变砖链 —— `robot-boot-check` + `robot-rescue`

这不是一个脚本，是**三个东西串起来的一条链**：

```text
robot-boot-check.timer（开机 3 分钟后）
        ↓ 判定这次 release 没起来
robot-rescue（把 current 换回 golden）
        ↓
golden 那个已知好的版本
```

#### 10.6.1 为什么是"定时器 + 死线"，而不是 `OnFailure=`

**最反直觉、也最值得学的一点**：它**没有**用 systemd 的 `OnFailure=` 来触发。

**原因**：`OnFailure=` 依赖"服务**失败**"这个事件 —— 但板子上这些守护进程全是 **`Restart=always` + 几秒的 `RestartSec`**。systemd 的默认判定是"**10 秒内启动 5 次**才算失败"，而一个每 5 秒重启一次的进程**永远达不到这个阈值** —— **它会一直重启，永远不"失败"，`OnFailure=` 永远不触发，救援永远不会发生。**

> **所以判据换成了一句"到时间还没好"**：`OnBootSec=180`。
> **为什么是 180 秒**：蓝牙适配器 `hci0` 在**上电约 73 秒**后才出现，而 `bluetooth.service` 还要在 dbus 后面**阻塞约 26 秒**。**死线必须晚于最慢的那条正常路径。**

#### 10.6.2 它怎么判定"没起来"

| 判据 | 值 |
| --- | --- |
| 只盯 4 个成员 | `updaterd` / `robotd` / `configd` / `btd` |
| 判定为坏 | `ActiveState == failed`，**或** 重启次数 `>= 3` |
| 开机超过 600 秒 | **放弃检查**（这台板子已经"活够久了"，别去动它） |

**为什么是"失败 或 重启次数过多"两条一起看**：单看"失败"会漏掉"疯狂重启但从没真正失败"的进程；单看重启次数会误伤"刚重启过一次的良性疾病"。**两条一起看，才既不漏、也不误伤。**

**它还内建了一条自我约束**（这份脚本把权衡写透了）：

> **"这里一个假阴性，代价是运维要去查一次；一个假阳性，代价是一次好好的 release 被回滚。"**
> 所以判据宁可**保守**：**宁可漏，不可误伤。**

**三种"它拒绝开火"的设计**：`Conflicts=shutdown.target`（正在关机时别掺和）、10 分钟在线守卫（刚开机那阵子别乱判）、**没有 `[Install]` 段**（它靠定时器拉起来，不该被 `enable` 成开机常驻服务）。

#### 10.6.3 `robot-rescue`：极简到"只读两个软链"

**它的全部逻辑**：读两个软链（`current` 和 `golden`），把 `current` 换成 `golden`。**不解析任何东西。**

**为什么"什么都不解析"是优点**：救援脚本运行在"系统已经不正常"的时候。**任何解析、任何依赖、任何"先看看情况"，都可能是压垮它的那根稻草。** 这条链上**每多一行代码，就多一个在关键时刻失败的理由**。

**它的几条硬规矩**：

| 规矩 | 为什么 |
| --- | --- |
| **退回 `golden`，不是退回"上一个版本"** | `keep_previous` 保的那个"上一个"**可能正是刚坏掉的那个**。救援要的是**已知好**，不是**最近** |
| 用 `mv -fT`（不是 `ln -sfn`） | `rename(2)` 是**原子**的：要么旧指针、要么新指针，**不存在"指针丢失"的中间态** |
| **先写面包屑、再换指针** | 面包屑写在 **swap 之前**，这个顺序是**刻意**的：即使换到一半断电，重启后**至少知道"这里救援过"** |
| 面包屑是 `key=value` 纯文本，不是 JSON | 能救命的格式要**能被任何工具打开**（`cat` 就够），**不需要解析器** |
| 没有 `golden` / `golden` 没装 / `current` 已经是 `golden` → **退出码 2 拒绝执行** | **拒绝也是一种答案**，而且比"假装做了一次救援"有用得多 |
| 有面包屑 → 拒绝重复救援 | **防循环**：救援本身把系统搞坏时，不要无限救下去 |

**`--dry-run` 是给谁用的**：给你。**任何"救命脚本"都应该能先空跑一遍**，看清楚它要动哪两个东西再执行。

---

### 10.7 三层编排 —— `provision-board.sh` / `provision.sh` / 子脚本

**先看分工，再看内容**：

| 层 | 在哪运行 | 职责 |
| --- | --- | --- |
| `provision-board.sh` | **你的 Windows 机器** | 唯一一个**不**在板子上跑的脚本。负责"把东西送上去、按顺序触发、把结果带回来" |
| `provision.sh` | **板子上**（SSH 进去之后） | 板子端的编排者 |
| `setup-board.sh` / `migrate-network.sh` / `install.sh` | 板子上 | 真正干活的三个 |

**它的核心设计声明（文件头原话，值得直接记住）**：

> **"它编排 `setup-board.sh`、`migrate-network.sh` 和 `install.sh`；它不重复它们。"**

**为什么这句话重要**：这是"**加一层**"和"**抄一遍**"的分界。编排脚本如果顺手把那三个脚本的活儿也干一遍，那么**下一次改 `setup-board.sh` 时，这一份就会被忘掉** —— 于是同一件事有了两个说法，而板子上跑的是旧的那个。

**它为什么总要多重启一次**：因为 `setup-board.sh` 改的是**内核启动参数 / 设备树 overlay** —— 这类改动**不重启不生效**。于是"布板"这件事的天然形状就是：**改 → 重启 → 再验**。（也正因如此，它必须保证重启后能自己接着跑下去。）

**防死循环的两个守卫（设计得很干净，值得抄）**：

| 守卫 | 机制 |
| --- | --- |
| **恢复单元先自我禁用、再干活** | 开机自动续跑的 `robot-provision.service` 第一件事是**把自己 disable 掉** —— 这样**万一它自己挂了，不会无限重启成循环** |
| **`migrate-network.sh` 只在"NM 已经接管 wifi"时才重跑** | 网络迁移是**唯一不可重入**的一步，所以给它加了**前置条件**（判断"是不是已经切过了"），而不是靠"重跑一次没事" |

**还有一段很现实的逻辑：DHCP 竞争 + 蓝牙兜底**。板子刚起来时网络还没拿到地址，而你要从 Windows 连它 —— **`provision-board.sh` 会在等不到地址时退回蓝牙（BLE）这条路**。这就是它为什么有那么多 `--no-ble` / `--pause-btd-on-pair` / `--weird-ble` 开关。

**它的常用开关（速查）**：

| 开关 | 作用 |
| --- | --- |
| `--ref <分支/tag>` | 要装哪个 ref（配合"开发板"就能装分支构建） |
| `--name <名字>` | 给机器人起名（之后 `dev-push.sh --name` 就靠它找到板子） |
| `--forget-host-key` | 板子重刷过、host key 变了时用 |
| `--local` | 用本地已下好的资产，不重新下 |
| `--no-dev-key` / `--dev-key <路径>` | 控制要不要信任 dev 签名（= 要不要让这块板子能装分支构建） |
| `--no-ble` | 不走蓝牙兜底 |
| `--pause-btd-on-pair` | 手柄配对不上时先试这个 |
| `--no-gstreamer` / `--no-rkaiq` | 跳过摄像头相关组件（没有摄像头时） |
| `--weird-ble` | **不要乱开**：给蓝牙行为异常的板子用的逃生舱口 |

**你要带走的那一条**：**编排层只做一件事 —— 按顺序调用，并且保证"中途断了能接着跑"。** 一旦它开始"顺便帮子脚本做点什么"，它就从"编排"退化成了"第二个真相"。

---

### 10.8 `dev-push.sh` —— 你的改动怎么走到板子上

**它在干吗**：在**你的开发机**上交叉编译 → 签名 → 送到板子 → 让板子**走正常的更新管道**装上。

**关键点一：用名字，不用地址**

```text
--name duck-c51b   → 走蓝牙广播名找板子（不需要知道 IP）
radxa@<板子IP>     → 直连
```

**为什么"名字"有时间价值**：IP 是 DHCP 分的、**会变**；名字不会。缓存放在 `$HOME/.cache/duck/boards`，板子上的用户默认是 `radxa`（`DUCK_BOARD_USER`）。**两个参数不能同时给** —— 那是用两种方式命名同一块板子。

**关键点二：两种交叉编译路径**

| 路径 | 命令 | 特点 |
| --- | --- | --- |
| zigbuild | `cargo board --bins` | 本机直接交叉编译，快；需要 `cargo-zigbuild` + `zig` |
| Docker | `cargo build --release --target aarch64-unknown-linux-gnu --bins` | 起一个 aarch64 构建环境；**Windows 上没有 zigbuild 时走这条** |

**关键点三：版本号长什么样、为什么**

```text
<crate>-dev.local.<epoch>.g<sha7>
```

- `<epoch>`（时间戳）让**每次**推送都是一个**新版本**，不会被"已经是这个版本了"挡掉；
- `<sha7>` 让你**从版本号就能反查是哪次提交** —— 板子上跑的是哪个 commit，一眼可读；
- **注意里面没有构建时间**：这是**测出来的**取舍 —— 带上构建时间会让每次构建都产生不同字节，触发**约 30 秒无谓的重建**。

**关键点四：四个动作，一个都不省**

```text
① 交叉编译
→ ② 签名（xtask sign --dir dist --key <私钥>）
→ ③ scp 送上去（它是 scp，不是 rsync）
→ ④ sudo robotctl update apply daemon --from '<远端目录>' --version '<版本号>'
```

**第 ④ 步才是重点**：它**不是**"把二进制拷过去覆盖"，而是一条**普通的 `update apply`** —— 也就是说，**它经过同样的预检、同样的健康门、同样的自动回滚**。

> **这就是为什么值得绕这一圈**：你本地那点改动，**沿着和正式发布完全相同的管道进板子**。它要是坏的，它会**自己滚回去**，而不是让你抱着一块砖。

**几个细节**：

| 细节 | 说明 |
| --- | --- |
| 私钥路径 | `$DUCK_DEV_SECRET_KEY`，默认 `~/.duck-keys/team.dev.key` |
| `--bootstrap` | **逃生舱口**：当"引导"这条正常路径本身有问题时绕过它。**名字的意思就是"我知道我在绕过什么"** |
| 退出码 2 | 表示**接口不匹配**（板子上的 `robotctl` 和你要推的东西对不上） |
| 它**不做**什么 | 不帮你配交叉编译环境、不帮你创建 dev key、不帮你把板子变成"开发板"（那是 §12 的三个前置条件） |

---

### 10.9 两个配置文件 —— 什么时候该改，什么时候**绝对别改**

板子上有两个 `toml`，它们遵循**完全相反**的两种哲学，搞混了会很难受。

#### A. `/etc/robot/*.toml` —— **运维的文件，一旦装上就被"冻结"**

| 事实 | 后果 |
| --- | --- |
| `install.sh` **只在第一次**拷贝它 | 之后**任何更新都不会动它** |
| 更新覆盖 `/opt/robot/**`，**不碰 `/etc`** | 所以它**能扛过更新和回滚**（这正是设计目的） |
| 同时也意味着：**你写进去的值会被冻在这块板子上** | **新 release 的默认值你永远拿不到** |

**这份文件里有一条"纪律"，值得抄到任何项目里**（`robotd.toml` 的注释写了它造成过的真实后果）：

> **每一行被注释掉的，都是"内置默认值"。除非这个机器人真的需要不同的值，否则让它保持注释状态。**
> 原因：`install.sh` 只拷一次、永不覆盖 —— **一个被取消注释的值会被永久冻在板子上，而 release 还在往前走。**
> 注释里写得很直白：这就是**一整个机队站在 kP 120 上、而 release 默认值早就写着 160** 的原因。

#### B. `updater.toml` vs `updater.example.toml` —— **两份文件，两种角色**

| 文件 | 角色 |
| --- | --- |
| `updater.example.toml` | **注疏版**：把**所有**选项都写出来，包括**故意没设**的那些。回答"**有可能怎么配**" |
| `updater.toml`（装在板子上的） | **事实版**：只写**这台出厂机器人真实的样子**。回答"**实际怎么配的**" |

原话把两者的关系说得很准：

> **"示例展示什么是可能的，这份展示什么是真的。两者不一致的地方，示例的注释解释这个选项是什么，而这份文件的注释解释为什么这么选。"**

#### C. `robotd.toml` 里**第一次就该看一眼**的几个值

| 键 | 教程里的期望值 | 说明 |
| --- | --- | --- |
| `[platform].variant` | `open_microduck` | **一行决定**舵机协议、IMU 从哪读、以及一组标定过的运行时数值 |
| `[bus].port` | **生产接线是 `/dev/ttyS2`** | ️ 见下面的警告 |
| `[imu].bus` | **生产接线是 `/dev/i2c-imu`**（i2c4、0x6A） | ⚠️ 见下面的警告 |
| `[policy].enabled` | 看你要不要跑策略 | **`false` 会让它"保持当前姿势"并且依然是健康的** —— 这是刻意留的台架配置，**不是降级** |
| `[policy].action_scale` | 走路默认 0.9（roller 0.8） | 本教程里改成 `0.3` 让它慢一点（§7 提过） |

> ️ **实测提醒（值得你自己去看一眼）**：仓库里的 `deploy/robotd.toml.walk` 模板写着 `port = "/dev/ttyACM0"`、`bus = "/dev/i2c-5"`，**而它自己的注释和本教程都写着生产接线是 `/dev/ttyS2` 和 `/dev/i2c-imu`**。
> 这**不一定是 bug**（注释里说了"接线不同的板子可以覆盖"、"有些板子会在 `/dev/i2c-5` 上应答"），但**它意味着：不能靠"默认值"来假设你的接线**。
> **上板子后第一件事就是确认这三个值**：
>
> ```bash
> grep -E '^(variant|port|driver|bus|address)' /etc/robot/robotd.toml
> ls -l /dev/ttyS2 /dev/i2c-imu        # 节点到底存不存在
> ```
>
> **这就是 §6.6.3 那条"静默失败"规则在配置文件上的版本：默认值不会报错，它只会让你以为自己对。**

---

### 10.10 教程里没提到的脚本 —— 它们是什么角色，要不要管

`microduck/scripts/` 下有 **23 个**脚本。上面已经拆了 8 个，剩下的这些**不需要你手动跑**，但**知道它们存在**能省很多困惑（尤其是"为什么更新的时候它会自己装东西"）。

| 脚本 | 角色 | 你要知道的一件事 |
| --- | --- | --- |
| `setup-gstreamer.sh` | 装 `mediad` 需要的 GStreamer 全套，并且**报告这块板子能编什么** | **由 `hooks/preinstall` 在每次更新时自动跑**，带 10 分钟上限、**没有 token** —— 这就是为什么插件源必须是公开的，而且它**绝不能弹交互** |
| `setup-rkaiq.sh` | 装 Rockchip rkaiq 3A 引擎 + IMX219 调参 | **不装的话画面是绿的、而且全是噪点**（ISP 用裸默认值在跑）；**曝光不归它管**（那是 `mediad` 的 exposure 模块的事） |
| `setup-npu.sh` | 装 NPU 运行时 `librknnrt.so`，并**报告驱动那一半在不在** | 它需要**两半**：驱动（在内核里，有就有、没有就没有）+ 运行时（厂商 blob，不在任何 Debian 源里）。**默认会顺手把设备树里的 NPU 节点打开**，因为 Armbian 在**每一块** Radxa Zero 3 上都是 `status = "disabled"` |
| `setup-login.sh` | 登录 shell 的三样小东西：`robotctl` 补全、印着当前 release 的横幅、提示符里带机器人名字 | **为什么它是独立脚本、而不是塞进 `install.sh`**：`install.sh` **只跑一次**，而这几样"每个版本都可能变"，所以必须**每次更新都跑一遍** |
| `board-test.sh` | 交叉编译 + 在容器里**真的跑一遍**验证 | **不是硬件的替代品**，但能抓住"只在开发机上不出现"的问题（交叉链接、glibc 下限、unix socket / 文件权限语义） |
| `systemd-test.sh` | systemd 单元相关测试 | CI 用，与你无关 |
| `pad-*.sh` / `provision-hls.py` / `bake-duck-mesh.py` / `cross-sysroot.sh` | 上位机 / 工具链 / 打包类工具 | 与"把这块板子跑起来"无关，本教程不展开 |

**这一节最值得带走的一条**（关于"每次更新都跑一遍"这件事）：

> `hooks/preinstall` / `hooks/postinstall` 是照着"**板子已经被布过、现在是来更新的**"这个前提设计的。
> 它的意义在于：**一块在 GStreamer / rkaiq / NPU 存在之前就布好的板子，靠一次普通更新就能被修好 —— 不需要有人记得去敲那条命令。**
> **而手动跑，是"重试"，不是"机制"。**

---

### 10.11 收束：这份教程里，其实只有三种脚本

把上面全部东西压成一张表。以后看到任何一个新脚本，**先归类**：

| 类型 | 例子 | 特征 | 什么时候该动它 |
| --- | --- | --- | --- |
| **一次性的 bring-up** | `setup-board.sh`、`migrate-network.sh` | 改的是**机器本身**（设备树、网络栈、内核参数）；跑对了就该退休 | 换硬件、重刷系统、apt 升级内核之后 |
| **幂等、每次更新都跑的** | `setup-gstreamer.sh`、`setup-rkaiq.sh`、`setup-npu.sh`、`setup-login.sh` | 改的是**运行时依赖**；**必须能在已经配好的机器上重复跑** | 基本不用手动动；手动跑 = 重试 |
| **编排 / 救援 / 开发** | `provision-*.sh`、`dev-push.sh`、`robot-rescue`、`robot-boot-check` | **不实现功能**，只负责"按顺序调"或"出事时兜底" | 出问题时；`robot-rescue` 是最后的救命路径 |

**看一个脚本属于哪一类，只看三件事**：

1. **它改的是"机器"还是"软件"？** → 机器 = 一次性；软件 = 可能要重复；
2. **它跑完还会不会被再跑一次？** → 会 = 必须幂等，而且必须能**在已配好的机器上**跑；
3. **它失败时，系统会不会跟着完蛋？** → 会 = 它是硬的一步，**必须自己带兜底**（像 `migrate-network.sh` 那样）。

> **最后一句话**：这份教程前面所有的"照着敲"，到这里应该已经全部变成了"**我知道这一下在动什么、失败了会长什么样、以及我为什么不能把它改成别的样子**"。
> **这才是"换个新机器人也能自己设计出来"的真正含义 —— 你带走的不是这些命令，是这套问法。**

---

## 11. 常见问题速查表

| 现象 | 先做什么 |
| --- | --- |
| 板子亮但进 initramfs / 找不到 root → 先看 §0.1~§0.6 的踩坑历史！ | 电源（换 90W 头）→ 烧录（换 Radxa OS + Etcher）→ 看 blkid 输出是 mmcblk 还是 mmcblk1 还是空 GPT |
| initramfs 里 ls /dev/mmcblk* 报 No such file | **电源不够！** 换小米 90W 头 + 粗 Type-C 线 |
| initramfs 里 blkid 只有 PTUUID + PTTYPE=gpt（没有 p1/p2 分区） | **烧录被 Windows 干扰了** → 用 Radxa OS + Etcher 重烧 |
| 无法 SSH / 连不上 | 先 ping 板子 IP → 看板子 IP 有没有变（DHCP 换地址是常态）→ 路由器租约表 |
| SSH Connection refused | 板子上没装 openssh-server → 本地终端跑`sudo apt install -y openssh-server && sudo systemctl enable --now ssh` |
| 重刷后 SSH 报"host key 变了" | 换卡重刷会重新生成 host key。删旧记录：`ssh-keygen -R 板子IP`，再连 |
| `/dev/ttyS2` 不存在 | setup-board.sh 没开 UART2 overlay → 手动改启动配置文件加`overlay_prefix=rk3568 overlays=uart2-m0` |
| 舵机全失联 | 大概率 agetty/内核 console 占着 ttyS2 → 查`fuser -v /dev/ttyS2` |
| `robotctl health` 报 unhealthy（裸板） | 舵机没电/没接，是诚实答案，不是安装失败 |
| apt 升级后舵机又看不到 | 内核升级可能重置 /boot 链接，重跑 setup-board.sh |
| 手柄配对不上 | 先试`--pause-btd-on-pair`，不行再 `--weird-ble`（不要乱开） |
| 板上日志找不到了 | `/var/log` 是内存，断电即失；持久记录是 `robotctl update log` |
| 板子没有 RTC → TLS 报错 | `timedatectl` 等 NTP 同步（Wi-Fi 连上后自动同步） |
| `robotctl` 报 `Permission denied (os error 13)` | `robot` 组没在当前 shell 生效 → `newgrp robot`（或重开 SSH），见 §8.4 |
| 装完后重跑 install.sh，版本号没变 | **设计如此**：已装 release 会跳过引导 → 用 `sudo robotctl update apply daemon` 升级，见 §7.3 |
| install.sh 下载资产报 404，但仓库存在 | 私有仓库忘了 `DUCK_TOKEN`（GitHub 用 404 掩盖 401）→ 设 token 并 `sudo -E` 重跑，见 §7.2 |
| install.sh 打印 `bootstrap binary does not match` | 引导二进制与签名 release 不一致 → **当"下载被篡改"处理**，不要重试掩盖，见 §7.3 |
| 更新装了，但某个守护进程还在跑**老二进制** | `on_apply.units` 是"补充清单"不是权威清单；老板子可能留着写死的 `units = ["robotd"]`，见 §10.5 |
| 改了 `/etc/robot/*.toml`，新 release 的默认值却不生效 | **设计如此**：`/etc` 不参与更新，你写进去的值会被**永久冻在板子上**，见 §10.9 |
| 不确定 `robotd.toml` 里的 `port` / `bus` 该怎么填 | **不要靠默认值假设接线** → `ls -l /dev/ttyS2 /dev/i2c-imu` 后再填，见 §10.9 |

---

## 12. 进阶：改一行代码，推到板子上

**整节在干吗**：搭起"改本地代码 → 一条命令装到板子上跑"的日常开发回路。

**为什么不直接 `scp` 个二进制上去**：因为那会绕开签名验证、健康门和自动回滚。走 `dev-push.sh` 意味着**你本地那点改动是沿着和正式发布完全相同的管道进板子的** —— 也就是说，如果它坏，它会自己滚回去，而不是让你抱着一块砖。

**三个前置条件（缺一就走不通）**：

| # | 条件 | 怎么确认 | 缺了会怎样 |
| --- | --- | --- | --- |
| 1 | **板子是"开发板"**（信任 dev 签名） | §8.3 的两条命令 | `--ref 分支` 被拒绝，报错像"签名损坏" |
| 2 | **dev 签名私钥**在 `~/.duck-keys/team.dev.key` | `ls -l ~/.duck-keys/team.dev.key` | 签名不了，推不出去 |
| 3 | **有交叉编译能力**（zigbuild 或 Docker，二选一） | 见 `onboarding.md` §5 | 编译不出 aarch64 二进制（在 Windows 上必然如此） |

**为什么需要交叉编译**：你的板子是 aarch64、开发机是 x86_64 Windows。要么用 zigbuild、要么用 Docker 起一个 aarch64 构建环境 —— **没法在 Windows 上直接编出能跑的二进制**。

**然后一条命令**：

```bash
scripts/dev-push.sh --name duck-c51b        # 按机器人名（走蓝牙问地址，不需要知道 IP）
scripts/dev-push.sh radxa@<板子IP>          # 或直接给地址
```

**两个参数的区别**：`--name` 是 `duckctl` 的"机器人名"（**用蓝牙广播名去找板子**，所以你不用知道 IP）；`radxa@<IP>` 是直连。**两个不能同时给** —— 那是用两种方式命名同一块板子。

**装坏了会怎样**：走的是普通更新管道 → **有健康门** → 判不健康就**自动回滚**。想故意回滚：

```bash
sudo robotctl update rollback daemon
```

> ️ 这一节是"以后的事"。**第一次部署先把 §1~§9 走完、§8.6 验收通过**，再来玩这条。
>
> 想看这一节背后"一次推送到底发生了什么"（版本号为什么长这样、为什么走 `update apply` 而不是覆盖二进制、`--bootstrap` 是什么意思）：**§10.8**。

---

## 13. 参考文档索引

| 想看什么 | 文件 |
| --- | --- |
| 中文路径图（"这是什么 → 我能跑吗"）  | `joyandai/microduck/docs/onboarding.md` |
| 从零装开发板（最短流程） | `joyandai/microduck/docs/robot/install-dev.md` |
| 每一步拆开手工做 | `joyandai/microduck/docs/robot/install-by-hand.md` |
| 全部`robotctl` 命令 | `joyandai/microduck/docs/robot/cheatsheet.md` |
| 分支构建/更新陷阱 | `joyandai/microduck/docs/robot/cheatsheet-dev.md` |
| 笔记本蓝牙控制 | `joyandai/microduck/docs/robot/duckctl.md` |
| 手柄配对细节 | `joyandai/microduck/docs/robot/pair-a-gamepad.md` |
| 镜像信任链/日志落盘（深度） | `joyandai/microduck/deploy/README.md` |
| 更新器内部设计（对应 §10.3 / §10.5）  | `joyandai/microduck/docs/design/updater-design.md` |
| 重启顺序 / 为什么 updaterd 和 btd 不重启（§10.5） | `joyandai/microduck/docs/design/restart-order.md` |
| `units` 写死清单那个 bug 的完整记录（§10.5） | `joyandai/microduck/docs/project/install-path-gap.md` |
| 开机自检 + 救援链设计（对应 §10.6） | `joyandai/microduck/docs/design/boot-recovery-net.md` |
| 蓝牙通道更新 + `btd` 权限（对应 §10.4） | `joyandai/microduck/docs/project/update-over-ble.md` |
| `dev-push.sh` 官方说明（对应 §10.8）  | `joyandai/microduck/docs/robot/dev-push.md` |
| 分层架构与"为什么配置要活过一次更新"（§10.9） | `joyandai/microduck/docs/design/architecture.md` |
| 底层诊断工具交叉编译（WSL） | `joyandai/microduck/docs/robot/bringup-examples.md` |
| 主控选型/板子参数 | `OpenMicroDuck/docs/main_controller.md` |
| 软硬件架构总览 | `OpenMicroDuck/docs/architecture.md` |
| Radxa Zero 3W / 3E 硬件差异（踩坑用） | `https://forum.armbian.com/topic/58329-radxa-zero-3w-emmc-not-detected-vmmc-supply-lookup-fails-in-dtb/` |

---

### 一句话收尾（已验证可行的最短路径）

**Radxa OS 官方镜像 + balenaEtcher 烧录 → 90W PD 头供电 → HDMI 接显示器看它起来 → Wi-Fi 连上并修好自动连（§0.7）→ 拿 IP → 免密 SSH → 跑 setup-board.sh 诊断 → 手动补它没覆盖的步骤（extlinux.conf）→ 装守护进程（`sudo -E sh ~/install.sh`）→ `newgrp robot` → 重启 → `robotctl health` 验收 → 再重启一次确认 headless 免密免键鼠。**

三个最容易翻车的点，再念一遍：

1. **电源**（§0.1）—— 5V 电压不会烧，但**电流不够会让 TF 卡整个消失**；
2. **烧录**（§0.2）—— 烧完别让 Windows 碰那张卡，尤其别点"格式化"；
3. **Wi-Fi 自动连必须在屏蔽图形登录之前修好**（§0.7）—— 否则一重启就连不上板子。

裸板报 `unhealthy` 是它诚实地告诉你"舵机还没接"，不是装坏了。

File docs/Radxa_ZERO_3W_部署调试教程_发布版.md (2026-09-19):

# Radxa ZERO 3W 部署与调试实战：从烧录系统到机器人守护进程

**摘要**：本文完整记录把一块全新的 Radxa ZERO 3W（RK3566 / 2GB LPDDR4 / 无 eMMC）从零配置为 Microduck 机器人主控的全过程 —— 选镜像、烧录 microSD、首次上电、SSH 免密登录、板级 bring-up、部署 Rust 守护进程（`robotd` 等）、验证与排障。文中所有命令、寄存器/设备地址、版本号、报错原文与判定标准均来自实机记录，可直接照做。**前置条件**：一块 Radxa ZERO 3W、≥16GB microSD 卡、5V/2A 以上电源、一台 Windows 开发主机，以及 Linux 命令行、SSH、PowerShell 的基本使用能力。全文按"先诊断、再动手"组织；文末附常见问题速查表、参考来源、待核实事项与更新日志。

**图例说明**（全文只用这一套标记）：

| 标记 | 含义 |
| --- | --- |
| **【动手】** | 会改变板子 / 存储卡状态的命令，执行前先确认清楚 |
| **【只读】** | 只看不改，可安全执行 |
| **【原理】** | 解释性内容，赶时间可跳过 |
| **⚠️** | 已知的坑、或容易失败的地方 |

> **关于路径**：下文出现 `<你的工作目录>`、`~/microduck` 或 `C:\Users\<你的用户名>` 的地方，请替换为你自己的本地路径；出现 `<板子IP>` 的地方，替换为板子的局域网地址（获取方法见 §5.2）。本教程使用的参考板为 Radxa ZERO 3W（2GB / 无 eMMC），实测数据见各节标注。

## 本文目录

- [0. 开篇：常见坑速览](#0-开篇常见坑速览)
  - [0.1 电源不足导致 TF 卡无法识别](#01-电源不足导致-tf-卡无法识别)
  - [0.2 Windows 烧录工具导致分区表被清空](#02-windows-烧录工具导致分区表被清空)
  - [0.3 Armbian 设备树缺少 ZERO 3W 专用 dtb](#03-armbian-设备树缺少-zero-3w-专用-dtb)
  - [0.4 PowerShell 管道展开环境变量报错](#04-powershell-管道展开环境变量报错)
  - [0.5 SSH 连接被拒绝：未安装 openssh-server](#05-ssh-连接被拒绝未安装-openssh-server)
  - [0.6 initramfs 中设备节点的三种状态](#06-initramfs-中设备节点的三种状态)
  - [0.7 重启后 Wi-Fi 不自动连接导致 SSH 失联](#07-重启后-wi-fi-不自动连接导致-ssh-失联)
- [1. 板子在项目中的角色](#1-板子在项目中的角色)
- [2. 准备清单](#2-准备清单)
- [3. 认识板子：接口与关键引脚](#3-认识板子接口与关键引脚)
- [4. 烧录系统到 microSD 卡](#4-烧录系统到-microsd-卡)
- [5. 用 SSH 登录](#5-用-ssh-登录)
- [6. 板级环境配置（bring-up）：先诊断再动手](#6-板级环境配置bring-up先诊断再动手)
  - [6.1 先跑七条诊断](#61-先跑七条诊断)
  - [6.2 获取脚本并放到板子上](#62-获取脚本并放到板子上)
  - [6.3 建立用户组](#63-建立用户组)
  - [6.4 运行 setup-board.sh](#64-运行-setup-boardsh)
  - [6.5 网络迁移：netplan 到 NetworkManager](#65-网络迁移netplan-到-networkmanager)
  - [6.6 setup-board.sh 逐段精读](#66-setup-boardsh-逐段精读)
  - [6.7 方法论：如何为新板子设计 bring-up](#67-方法论如何为新板子设计-bring-up)
- [7. 部署 microduck 软件栈](#7-部署-microduck-软件栈)
  - [7.0 先确认前置条件](#70-先确认前置条件)
  - [7.1 确认仓库与版本：三个环境变量](#71-确认仓库与版本三个环境变量)
  - [7.2 设置环境变量](#72-设置环境变量)
  - [7.3 执行安装](#73-执行安装)
  - [7.4 装完必须重启一次](#74-装完必须重启一次)
  - [7.5 国内网络三项修复](#75-国内网络三项修复)
  - [7.6 一条命令完成全部](#76-一条命令完成全部)
- [8. 验证部署是否成功](#8-验证部署是否成功)
- [9. 调试：从浅到深](#9-调试从浅到深)
- [10. 拆箱总纲：还有哪些黑箱与怎么拆](#10-拆箱总纲还有哪些黑箱与怎么拆)
- [11. 常见问题速查表](#11-常见问题速查表)
- [12. 进阶：改一行代码推到板子](#12-进阶改一行代码推到板子)
- [13. 参考文档索引](#13-参考文档索引)
- [参考来源](#参考来源)

---

## 0. 开篇：常见坑速览

这一节把最容易卡住的几个点提前讲完，按影响程度排序。**建议在动手前先通读一遍**，能省下数小时。

### 0.1 电源不足导致 TF 卡无法识别

- **症状**：板子亮、HDMI 有输出、内核起来了，但 initramfs 里 `ls /dev/mmcblk*` 报 `No such file or directory`；
- **根因**：5V/1A 的旧充电头 + 细 Type-C 线电流不够，RK3566 的 SDIO 控制器起不来；
- **修法**：换一个 **5V/2A 或 3A** 的充电头 + **粗一点的 Type-C 线**（例如 90W PD 快充头 + 5A 粗线，实测解决）。**电压必须是 5V（Type-C 默认），不会烧板子，大电流可以放心用**；
- **验证**：换电源后重上电，`blkid` 应能看到 `/dev/mmcblk1`（本教程参考板无 eMMC，SD 卡走 mmcblk1；有 eMMC 的板子 SD 卡走 mmcblk0）。

### 0.2 Windows 烧录工具导致分区表被清空

- **症状**：Armbian imager 校验显示"写入成功"，但板子启动后 initramfs 里 `blkid` 只看到 `/dev/mmcblk1: PTUUID=... PTTYPE="gpt"`（**空 GPT 分区表**——只有一张分区"目录"，实际 p1/p2 分区内容全丢了）；
- **根因**：Windows 上的 Armbian imager / Etcher / Rufus 在写入后会被 Windows 的**分区管理安全机制**干扰——Windows 看到一个带 GPT 头但没有有效分区的磁盘时，可能自动重新生成一张空 GPT，把镜像实际写入的分区内容覆盖掉；
- **修法**（三选一，按推荐顺序）：
  1. **换 Radxa OS 官方镜像 + balenaEtcher 烧录**（本教程推荐，已验证成功，见 §4）；
  2. 确实要用 Armbian → 用 **Win32 Disk Imager** 或 **WSL 里的 `dd`**（直接操作块设备扇区，绕过 Windows 分区管理）；
  3. 烧完后**立刻弹出 TF 卡，不要在 Windows 上点任何"格式化"、"修复驱动器"、"扫描"弹窗**。

### 0.3 Armbian 设备树缺少 ZERO 3W 专用 dtb

- **症状**：板子能启动但 Wi-Fi 不工作 / eMMC 不识别 / 某些 GPIO 控制器找不到；
- **根因**：Armbian 26.8.1 的 vendor 内核（6.1.115）**只 ship 了 `rk3566-radxa-zero3.dtb`，没有 3W 专用的 `rk3566-radxa-zero-3w.dtb`**——3W 有 Wi-Fi/BT 模块（aic8800），占用 SDMMC1 控制器，设备树必须包含对应的 pinctrl/regulator 配置；
- **修法**：直接用 **Radxa OS 官方镜像**（它自己维护设备树，自动识别 ZERO 3W / 3E），绕开这个问题。

### 0.4 PowerShell 管道展开环境变量报错

- **症状**：下面这种写法

  ```powershell
  type $env:USERPROFILE\.ssh\id_ed25519.pub | ssh user@ip "cat >> ~/.ssh/authorized_keys"
  ```

  会报 `Get-Content : 无法将参数绑定到"Path"，因为该参数是空值`；
- **根因**：PowerShell 管道 + 环境变量展开 + 用户名含非 ASCII 字符这三个因素叠加触发的 bug；
- **修法**：**不用管道**，改用 `scp` 直接把公钥文件拷到板子，再在板子上手动合并（见 §5.4）。

### 0.5 SSH 连接被拒绝：未安装 openssh-server

- **症状**：板子能 ping 通、IP 正确、但 `ssh` 报 `Connection refused`；
- **根因**：Radxa OS 出厂**没装 openssh-server**（或装了但没启动）；
- **修法**：在板子的本地终端（HDMI + 键盘）跑

  ```bash
  sudo apt install -y openssh-server && sudo systemctl enable --now ssh
  ```

### 0.6 initramfs 中设备节点的三种状态

在 initramfs 里用 `ls /dev/mmcblk*` 的输出可以区分三种情况：

| 情况 | `ls /dev/mmcblk*` 输出 | 根因 |
| --- | --- | --- |
| ❌ 卡完全没读到 | `No such file or directory` | 电源不够！换大电流充电头 / 粗线 |
| ⚠️ 卡读到但空分区 | `/dev/mmcblk1` 存在，但 `blkid` 只有 `PTUUID=... PTTYPE=gpt`（没有 p1/p2） | 烧录被 Windows 干扰了，换 Radxa OS + Etcher 重烧 |
| ✅ 正常 | `/dev/mmcblk1p1` + `/dev/mmcblk1p2` 都有，`blkid` 输出带 `UUID=` 和 `TYPE=` | 烧录正确，UUID 对得上 cmdline.txt 就能启动 |

### 0.7 重启后 Wi-Fi 不自动连接导致 SSH 失联

- **症状**：在桌面 / 终端里手动连上 Wi-Fi 后一切正常，但**重启后板子不联网、SSH 连不上**；接上显示器，只要**选账户输一次密码登录**，Wi-Fi 立刻自己就通了——看着像"必须先登录才行"，其实是**密码取不到**；
- **根因**：这个 Wi-Fi 连接的密码（PSK）是**以用户身份**保存的：Keyfile 里写着 `psk-flags=1`（agent-owned），**文件里根本没有 `psk=` 这一行**。NetworkManager 开机时以 root 身份运行，取密码要靠桌面会话里的 `secret agent`；而屏蔽 sddm（图形登录）之后，开机**没有任何用户会话 → 没有 agent → 直接判失败**：

  ```text
  (wifi) access point '<你的WiFi名>' has security, but secrets are required.
  no secrets: No agents were available for this request.
  state change: need-auth -> failed (reason 'no-secrets')
  Activation: failed for connection '<你的WiFi名>'
  ```
- **一眼确诊**（在还能连上的时候跑）：

  ```bash
  sudo grep -n -E "psk-flags|^psk=" /etc/NetworkManager/system-connections/*.nmconnection
  ```

  看到 `psk-flags=1` 且**没有** `psk=` → 就是这个坑；
- **修法**（一条命令，把密码改成"系统所有"，开机不需要任何会话）：

  ```bash
  # 自动取 UUID，避免手输中文 SSID 踩 IME 坑
  UUID=$(nmcli -t -f UUID,TYPE connection show | awk -F: '$2=="802-11-wireless"{print $1; exit}')
  echo "$UUID"

  sudo nmcli connection modify "$UUID" wifi-sec.psk "<你的WiFi密码>" wifi-sec.psk-flags 0
  # 顺手把持久化属性一次配齐
  sudo nmcli connection modify "$UUID" \
    connection.autoconnect yes \
    connection.autoconnect-priority 100 \
    connection.autoconnect-retries -1 \
    802-11-wireless.powersave 2

  sudo reboot
  ```

  **验收**：重启后**不接显示器、不做任何登录**，等 90 秒直接

  ```powershell
  ssh radxa@<板子IP>
  ```

  能直接进 = 修好了（显示器上仍旧停在 `login:` 属于正常，与联网无关）；
- **两个小坑**：

  1. `nmcli connection modify` 设置时可以用别名 `wifi-sec.psk-flags`，但 `nmcli -f` **查询字段必须写全名** `802-11-wireless-security.psk-flags`，否则报 `invalid field`；
  2. 改完密码会**明文**存在 `/etc/NetworkManager/system-connections/*.nmconnection`（权限 `600`，仅 root 可读）——这是 NetworkManager 的标准做法，不是配置错误；
- **不需要排查的方向**（别浪费时间）：`wpa_supplicant` 是 active **属于正常**（Debian 上 NetworkManager 通过 D-Bus 调它做 WPA 握手），不是"抢占网卡"；`systemd-networkd` 应该 inactive。

---

## 1. 板子在项目中的角色

这一节先确认型号和它在整机里的职责，避免后面把时间花在"这块板子到底是不是 ZERO 3W"上。

> **型号先确认清楚**：Radxa 官方**没有**一块叫 "ZERO 3" 的板子——**"ZERO 3" 只是这一代的系列名 / 文档目录名**，实际在售的只有两个型号：

| | Radxa**ZERO 3W** | Radxa**ZERO 3E** |
| --- | --- | --- |
| 无线 | ✅ Wi-Fi 6 + BT 5.4（AIC8800D80） | ❌ 没有 |
| 有线 | ❌ 没有网口 | ✅ 千兆以太网（支持 PoE，需另配 HAT） |
| 存储 | 板载 eMMC**0**/8/16/32/64GB 可选 + microSD | 只有 microSD |
| SoC / 内存 / 尺寸 | RK3566 / LPDDR4 1~8GB / 65×30mm | 与 3W 相同 |

> **本教程参考板 = ZERO 3W（eMMC 0GB 的 SKU）**：Wi-Fi 能连 + 没有 eMMC + 没有网口，三条特征全中，只可能是 3W。所谓"无 eMMC"不是另一个型号，而是 3W 的存储选配（0GB）。
>
> 被绕晕的来源：镜像名 `radxa-zero3_bookworm_kde_b1`、主机名 `radxa-zero3`、文档目录 `/zero/zero3/`——**两个型号共用这套命名**，到处写着 "zero3"，但它不代表型号。
>
> 想再确认一次——**注意 `/proc/device-tree/model` 在 3W 和 3E 上都只打印通用的 `Radxa ZERO 3`，不带 W/E 后缀**（2026-09-15 在真机上验证过），所以别靠它区分型号：

```bash
ls /sys/class/net/                      # 有 wlan0 → 3W；有 eth0 → 3E（3E 无无线，3W 无网口）
ls /dev/mmcblk*                         # 只有 mmcblk1 → 无 eMMC；另有 mmcblk0/mmcblk2 → 有 eMMC
cat /proc/device-tree/model; echo       # 只会打印通用串 "Radxa ZERO 3"
```

Radxa ZERO 3W 是机器鸭的**"大脑 / 主控"**。整台 Microduck（约 25 cm、800g 的双足小鸭）由它负责：

- 跑一个 **50 Hz 控制回路**，读 15 个舵机 + 机身 IMU，组 61 维观测，用 ONNX 神经网络（强化学习策略）推理，输出 14 个关节目标，驱动舵机走路 / 站立 / 踢球 / 翻滚 / 起身；
- 一组 Rust 守护进程：`robotd`（控制 / 电机）、`configd`（Wi-Fi / 名字 / PIN）、`updaterd`（签名更新 / 回滚）、`btd`（蓝牙门面）、`padd`（手柄）、`mediad`（相机 / 推流）、`tofd`（头部深度传感器）；
- 板载 Wi-Fi + 蓝牙：手机 App（BLE）、游戏手柄、远程 WebRTC 都走这里。

**关键概念（先记住这三个，后面都好懂）：**

1. **走路策略在 CPU 上跑 ONNX Runtime（ORT），不在 NPU 上。** NPU 是给"视觉 / 鸭子检测"预留的，且默认是关的。所以"2GB RAM、无 eMMC"对走路这一关没有任何影响——官方那档甚至只有 1GB RAM。
2. **只有 `robotd` 能碰电机。** 其它进程（手柄、手机、脚本）发的都是"意图"，由 `robotd` 内部的安全层决定是否执行。
3. **更新 = 整目录替换 + 验签 + 健康门 + 自动回滚。** 装坏了自己会滚回去，不是打补丁。

> 2GB 内存比官方 1GB 档还多，只会更充裕。**无 eMMC 不是缺陷**：意味着从 microSD 卡启动（对零基础反而更简单，不需要进入 USB 烧录的 maskrom 模式），只是存储介质换成卡。

---

## 2. 准备清单

这一节列出开始前需要备齐的物料，其中电源和 microSD 卡是最容易出问题的两项。

| 物品 | 要求 / 建议 | 用途 |
| --- | --- | --- |
| **microSD 卡** | **≥16GB，建议 32GB**，**A1/U3 速度等级**（Class 10 起步），正规品牌（SanDisk/Samsung/Kingston） | 系统就装在这张卡里（无 eMMC，卡就是硬盘） |
| **读卡器** | USB 读卡器（如果电脑没 SD 槽） | 写镜像到卡 |
| **电源** | **5V / 2A 或更高** 的 USB-C 充电头 + **粗一点的 Type-C 线**（90W PD 头 + 5A 粗线实测可用） | 供电。电流不够 TF 卡 / 外设起不来 |
| **Micro-HDMI 转 HDMI 线** | 1 条（强烈建议第一次用） | 第一次开机接显示器，直接看到它有没有起来  |
| **USB 键盘 / USB HUB** | 第一次接线用（可选，但出问题时救命） | 直接登录；没有就用 SSH |
| **Wi-Fi** | 能上网的 2.4G/5G 路由，且**知道密码** | 3W 没有网口，联网只能走 Wi-Fi |
| **能登录路由器后台** | 知道管理员地址（常见`192.168.31.1` / `192.168.1.1`） | 查板子的局域网 IP |

**电源选择速记：电压必须 5V（Type-C 默认，不会烧），电流越大越好（5V/3A、5V/5A、90W PD 头都 OK）。PD 头不会烧板子——板子只会按需取电流，多余的电流"空转"。**

---

## 3. 认识板子：接口与关键引脚

这一节速览板子接口，并列出后面调试时会反复见到的设备名与总线。

- 尺寸 **65 × 30 mm**，和树莓派 Zero 一个外形、同样的安装孔位；
- 两个 USB-C：
  - **USB 2.0 OTG / PWR**（用于**供电**，一般插电源的那头，这个口电流能力更强）
  - **USB 3.0 Host**（可接键盘 / 鼠标 / 摄像头等外设，**别拿这个口供电**，电流能力弱）
- **Micro HDMI**（输出显示，最高 1080p60）
- **microSD 卡槽**（系统所在处，无 eMMC 的板子**只能从这里启动**）
- **22 针 CSI 排线座**（摄像头）
- **40 针 GPIO**（3.3V，连到 HAT / 扩展板上，舵机总线、IMU、ToF、喇叭都走这里）

和机器人硬件相关的关键引脚（后面调试时会反复见到的设备名）：

| 功能 | 设备路径 | 说明 |
| --- | --- | --- |
| 舵机总线 | `/dev/ttyS2`（UART2） | 15 个舵机 + 机身 IMU 共用一条半双工 TTL 总线 |
| 机身 IMU | `/dev/i2c-imu`（i2c4，地址 `0x6A`） | LSM6DSV16X，独立总线（2026-09-04 起从舵机总线上拆出来了） |
| 音频 codec + 头部 ToF | `/dev/i2c-pihat`（i2c3） | TLV320AIC3104 codec（`0x18`）+ VL53L5/8CX 深度传感器（`0x29`） |
| 喇叭数据 | I²S3 | 声音不走策略网络 |
| 摄像头 | CSI | IMX219 一类模组 |

---

## 4. 烧录系统到 microSD 卡

这一节解决"系统盘怎么造"的问题。结论先行：

> **推荐路径**：Windows + Armbian imager / Etcher 烧 Armbian 镜像在 Zero 3W 上会出现"空 GPT 分区表"问题。**直接用 Radxa OS 官方镜像 + balenaEtcher**，实测成功。

```mermaid
flowchart TD
    A1["选镜像：Radxa OS 官方镜像（6.1 内核）"] --> A2["用 balenaEtcher 写入 microSD 卡"]
    A2 --> A3["插卡回板子 → 供电 → 首次上电"]
    A3 --> A4["观察串口 / HDMI 现象"]
    A4 --> B1{"起来了没有？"}
    B1 -->|"起来了"| C1["进入 §5：用 SSH 登录"]
    B1 -->|"没起来"| C2["按 §0 的坑逐项排查"]
    C2 --> D1["§0.1 电源不足"]
    C2 --> D2["§0.2 Windows 烧录工具"]
    C2 --> D3["§0.3 设备树缺少 ZERO 3W 专用 dtb"]
    C2 --> D4["§0.7 Wi-Fi 不自动连接"]
```

> **图 1**：从选镜像到首次起来的流程，以及"起来了 / 没起来"两条分支各自去哪一节。

### 4.1 【动手】下载 Radxa OS 官方镜像

- **官方下载页**：`https://docs.radxa.com/zero/zero3/download`
- 找**官方镜像**区块，下载 **6.1 内核的那个**：`radxa-zero3_bookworm_kde_b1`
  - 文件是 `.img.xz` 压缩包（约几十到几百 MB）；
  - **不用解压**，Etcher 支持直接写 xz 压缩包；
  - 如果 GitHub 下载慢，Radxa 页底部有百度网盘镜像。

**在干吗**：在挑一块"装机盘"。这块板子**没有 eMMC**（没有板载硬盘），操作系统没有任何地方可去，只能整份装在 microSD 卡里——所以这一步选的不是"一个软件"，而是这块板子的**整个硬盘内容**。

**为什么必须做 / 为什么只能是 Radxa OS**：两个理由，都在 §0 里踩过——① Armbian 镜像在 Windows 上烧会出现"空 GPT 分区表"（§0.2）；② Armbian 的设备树里只有通用的 `rk3566-radxa-zero3.dtb`，没有 3W 的 Wi-Fi 配置（§0.3）。Radxa OS 是板厂自己维护的，设备树天然对得上这块板子，Wi-Fi、SD 卡、GPIO 开箱即用。

**为什么是 6.1 内核那个**：同页面还有 5.10 内核的旧版（`radxa-zero3_debian_bullseye_xfce_b6`）。选新不选旧——后面的 ONNX Runtime、NetworkManager 版本都更配合新版 Debian。

**完成标志**：本地有一个 `.img.xz` 文件，大小对得上页面标注的数值。

**卡住了怎么办**：GitHub 直连慢 / 断 → 用页面底部的百度网盘镜像。下载完可以顺手核对页面给的 SHA256（不是必须）。

> 备注：Radxa OS 只有 KDE 桌面版（没有 Minimal/CLI 版）。2GB RAM 能跑，后面装完机器人驱动可以一键卸掉 KDE 省空间。

### 4.2 【动手】下载 balenaEtcher

- Windows 版下载：`https://github.com/balena-io/etcher/releases/download/v1.18.11/balenaEtcher-Setup-1.18.11.exe`
- 官方镜像页也推荐 Etcher（Radxa 自己都用它）。

**在干吗**：装一个"写盘工具"。它的作用等价于 Linux 的 `dd`——把镜像文件**逐扇区原样**写进 SD 卡，包括分区表、引导记录、文件系统。

**为什么必须做 / 为什么不能用资源管理器复制**：Windows 把 SD 卡当成"U 盘"，只能往里丢文件；而"可引导的系统盘"需要分区表和引导扇区，这是资源管理器和"格式化为 FAT32"都做不到的。把 `.img.xz` 拷到卡里，板子是绝对启动不了的。

**完成标志**：`balenaEtcher` 能打开（安装时 Windows 可能弹 UAC，允许即可）。

### 4.3 【动手】烧录步骤

> **按顺序执行，不要跳步。**

1. **TF 卡插进电脑读卡器** → 等 Windows 识别到盘符；
   - *在干吗*：让卡以"可移动磁盘"的身份出现在 Windows 里，Etcher 才看得见它。
   - *先记两个东西*：它的**盘符**（比如 `E:`）和**容量**（比如 29.7GB）。下一步要靠这两个认卡——尤其容量。
2. **打开 Etcher** → 点 **「Flash from file」** → 选刚才下的 `.img.xz` 镜像；
   - *在干吗*：告诉 Etcher"要写什么"。xz 是压缩包，**不用解压**，Etcher 边解压边写。
   - *为什么先选镜像再选盘*：Etcher 的默认流程是「选镜像 → 选目标 → 写入」；先选镜像，它才好过滤掉不合理的目标（比如系统盘）。
3. **点「Select target」** → **务必认准 TF 卡容量**（Windows 里会显示成 "29.7GB / 31.3GB" 之类的可移动磁盘，**绝对不要选电脑硬盘**）；
   - *在干吗*：告诉 Etcher"往哪写"。
   - ⚠️ **这一步是整个教程里唯一会毁数据的操作**：选错盘 = 把电脑硬盘整个覆盖掉，且不可恢复。**认容量不认盘符**（盘符会变，容量不会）。拔掉其他 U 盘 / 移动硬盘再选，更保险。
4. **点「Flash!」** → 等进度条走完 → Etcher 会自动校验；
   - *在干吗*：写盘 + **读回来逐字节比对**（这就是 Etcher 比"复制粘贴"靠得住的地方）。
   - *校验失败怎么办*：说明卡有坏块或读卡器不稳。**必须重烧，不要抱侥幸**——侥幸的结果就是 §0.2 那种"烧录显示成功、启动却找不到 root"。
5. **烧完立刻弹出 TF 卡**（Etcher 会提示 "Flash Complete!"）；
   - *在干吗*：把卡从 Windows 的管辖里摘出来，让它不再被系统"顺手"动到。
6. **别在 Windows 上做任何后续操作**——如果 Windows 弹"是否格式化此盘"、"驱动器需要修复"、"扫描"之类的弹窗，**一律点「取消」/「关闭」**。
   - *为什么*：见 §0.2。Windows 看到一个"有 GPT 头但分区不合法"的磁盘，会"好心"重新生成一张空 GPT，把刚才写进去的内容盖掉。一旦格式化，系统就没了——**这是最常见的翻车点**。

**完成标志**：Etcher 显示 `Flash Complete!`，而且**一次都没点过** Windows 的格式化 / 修复弹窗。

**卡住了怎么办**：见 §0.2 的三选一（换 Radxa OS + Etcher 已是最优解）；若 Etcher 写一半报错，换读卡器或换卡再试。

### 4.4 【动手】插卡回板子 → 供电 → 上电

1. TF 卡插进板子卡槽 → **按到底，听到"咔哒"一声锁牢**（再按一下能弹出来那种）；
   - *在干吗*：给板子装上它的"硬盘"。**没插到底 = 没有硬盘** → 板子会掉进 initramfs 报 `No such file or directory`（§0.1 / §0.6 的正面复现）。
2. USB 2.0 OTG / PWR 口接 **PD 头 + 粗 Type-C 线**；
   - *为什么是这两个口里的 OTG/PWR*：见 §3——另一个 USB 3.0 Host 口电流能力弱，**别拿它供电**。
   - *为什么要"粗线 + 大电流头"*：见 §0.1。RK3566 的 SD 控制器在电流不足时**根本起不来**，表现是"板子亮、有输出、但卡一个设备节点都没有"，极难往电源上想。电压 5V 不会烧，电流越大越安全。
3. Micro-HDMI 接显示器；
   - *在干吗*：第一次开机必须有"眼睛"。没显示器就只能靠串口猜，出问题几乎没法查。
4. 上电 → 等 **30~60 秒**；
   - *为什么慢*：首次启动要做一堆一次性动作——扩展 rootfs 到整张卡、生成 SSH host key、生成 machine-id、初始化 KDE 用户目录。**第一次慢是正常的，慢到 2 分钟也别拔电。**
5. **预期出现 KDE 桌面**（不是命令行！是图形桌面）。
   - *这说明什么*：**能进桌面 = 电源、SD 卡、烧录、设备树四关全过**。到这里为止的常见坑（§0.1~§0.3）就全部越过去了。

**首次登录凭据**：

- Radxa OS 出厂默认账号：**用户名 `radxa`，密码 `radxa`**（登录后会强制改密码，先记住改后的那个）。

**卡住了怎么办**：

| 看到的 | 说明什么 | 去哪 |
| --- | --- | --- |
| 黑屏 / 无 HDMI 输出 | 板子没起来，或线 / 显示器接口不对（注意是**Micro**-HDMI） | 先换线换屏；仍不行查 §0.1 电源 |
| 掉进`initramfs` / `(initramfs)` 提示符 | 卡没读到、或分区表坏了 | §0.6 的三种情况对照表 |
| 一直停在 Radxa 的启动 logo | 卡读到了但 rootfs 挂不上 | §0.2（烧录被 Windows 干扰） |
| 进了命令行而不是桌面 | 可能是 KDE 启动失败 | 先用命令行继续（后面 §5 照样能走），再查`journalctl -b` |

---

## 5. 用 SSH 登录

这一节把"必须坐在板子跟前接键鼠"变成"从 Windows 远程敲命令"。SSH = 从 Windows 电脑远程登录板子的命令行。Windows 10/11 自带 `ssh` 和 `scp`，不需要装任何东西。

**为什么必须做**：板子最终要 headless 装在鸭子身体里（25cm、800g，不可能挂个显示器），而且后面每一步（拷脚本、跑安装、看日志）都在板子上敲。做完这一节，HDMI 线和键盘就可以永久撤掉了。

**本节顺序不能乱**：5.1 连网 → 5.2 拿 IP → 5.3~5.4 装公钥 → 5.5 验证。中间任何一步跳了，后面都连不上。

### 5.1 【动手】确认板子已连上 Wi-Fi

> **在干吗**：让板子自己有网。3W **没有网口**，联网只有 Wi-Fi 一条路；没网就没有 IP，没有 IP 就没有 SSH。
> **完成标志**：网络图标显示已连接，或 `nmcli -t -f DEVICE,STATE device status` 里 `wlan0:connected`。

如果 Radxa OS 没自动连 Wi-Fi，手动连（两种方式任选）：

- **图形方式**：任务栏右下角网络图标 → 选 Wi-Fi → 输密码；
- **命令行方式**：在 Konsole 终端（KDE 自带，左下角应用菜单搜 Konsole）里跑：

  ```bash
  sudo nmcli device wifi connect "<你的WiFi名>" password "<密码>"
  ```

> **如果命令行连不上、或 SSID / 密码里有中文**：用 `nmtui`（全键盘操作的界面，能避开中文 IME 的坑）：
>
> ```bash
> sudo nmtui
> ```
>
> 进去后选 **Activate a connection** → 选中 Wi-Fi → 输密码。
> ⚠️ 注意：`nmtui` 的 **Activate a connection 只是"连一次"**，想让它开机自动连，得进 **Edit a connection** 把 `Automatically connect` 勾上 `[X]`——但更推荐直接用 §0.7 的 `nmcli connection modify` 一条命令搞定。

> ⚠️ **连上之后，务必先做 §0.7 的那次检查**（`grep psk-flags /etc/NetworkManager/system-connections/*.nmconnection`）。
> 如果密码被存成了"用户密钥环"（`psk-flags=1`），那么在 §6 屏蔽掉 sddm（图形登录）之后，**板子重启就再也连不上 Wi-Fi、SSH 直接失联**，只能接显示器键盘去救。**这一步必须在屏蔽 sddm 之前做完。**

### 5.2 【只读】获取板子 IP 地址

> **在干吗**：问板子"你在局域网里的门牌号是多少"。后面所有 `ssh` / `scp` 命令都要填这个地址。
> **为什么是 wlan0**：3W 只有无线网卡，所以地址一定在 `wlan0` 上（有线是 `eth0`，3W 没有）。

在板子的 Konsole 里：

```bash
ip addr show wlan0
```

找 `inet` 后面那串地址（形如 `192.168.1.42`），**记下来**。

也可以去路由器后台（比如 `http://192.168.31.1`）的 DHCP 租约表里看"已连接设备"。

> ⚠️ **这个地址会变**：路由器按 DHCP 分配，重启路由器 / 隔几天不看，板子可能就换成别的地址了。**SSH 突然连不上、但板子明明开着**——第一件事是去路由器后台重新看它的地址，别急着怀疑板子坏了（§11 速查表里也有这条）。

**完成标志**：能背下 / 贴出这个 IP。

### 5.3 【动手】在 Windows PowerShell 里生成 SSH 密钥（一次性）

> **在干吗**：造一对"钥匙"。SSH 免密登录的原理是**非对称加密**——生成一对数学上配对的密钥：

| 文件 | 放哪 | 作用 |
| --- | --- | --- |
| `id_ed25519`（**私钥**） | 留在 Windows，**永远不要给任何人** | 相当于钥匙本身 |
| `id_ed25519.pub`（**公钥**，`.pub` 结尾） | 拷给板子 | 相当于锁芯：板子拿它来验证"敲门的人手里有没有配对的钥匙" |

> 所以下面拷过去的**永远是 `.pub` 那个文件**，别拷错。
> **为什么用 ed25519**：现代默认算法，比老式的 RSA 更短、更快、更安全，Windows/Linux 都原生支持。

打开 **Windows PowerShell**（不是 CMD）：

```powershell
ssh-keygen -t ed25519
```

一路回车（提示保存路径回车、passphrase 回车设为空），会在 `C:\Users\<你的用户名>\.ssh\` 生成 `id_ed25519.pub`（公钥）和 `id_ed25519`（私钥）。

> **passphrase 为什么留空**：留空 = 用私钥时不再要你输密码，后面的脚本才能自动连。如果在意安全，可以设一个，但那样每次 `ssh` / `scp` 都要手输一次，后面的自动化步骤会卡住。

**完成标志**：`C:\Users\<你的用户名>\.ssh\` 目录下出现了 `id_ed25519` 和 `id_ed25519.pub` 两个文件。

### 5.4 【动手】把公钥放进板子

> **为什么不用 PowerShell 管道**：见 §0.4，`type xxx.pub | ssh ...` 这类写法容易报错，改用 `scp` 最稳。
>
> **整节在干吗**：把 5.3 生成的公钥"登记"到板子的 `~/.ssh/authorized_keys` 里。这个文件就是板子的"白名单"：里面列了谁的钥匙可以直接进来。
> **为什么不一步到位**：因为此刻还没有免密——**先用密码把公钥送进去，之后才能免密**。这是先有鸡后有蛋的顺序。

#### 步骤 1：scp 拷公钥文件到板子的 /tmp

> **在干吗**：`scp` = "走 SSH 通道的文件拷贝"（secure copy）。它连过去时用的还是**密码**认证。
> **为什么先落到 `/tmp`**：`/tmp` 是临时目录，谁都能写，不需要额外权限；真正"安装"公钥的动作（下一步）要有正确的权限和目录结构，在板子上做更稳。

```powershell
# 把下面的 <板子IP> 换成你刚查到的地址
scp "C:\Users\<你的用户名>\.ssh\id_ed25519.pub" radxa@<板子IP>:/tmp/
```

- 首次连接会提示 `Are you sure you want to continue connecting` → 输入 `yes` 回车；
  - *这是在干吗*：SSH 在问"这台板子的指纹我没见过，你确定这是你的板子吗"。第一次当然是 `yes`，之后它会记到 `known_hosts` 里，不再问。
- 提示输入板子密码 → **输入 `radxa`**（或登录时改后的那个密码）；
- 没输出就表示成功。

> ⚠️ **别用 `type xxx.pub | ssh ...` 这种管道写法**：见 §0.4——PowerShell 的管道 + 环境变量 + 非 ASCII 用户名三个因素叠在一起会报 `Get-Content : 无法将参数绑定到"Path"`。`scp` 一个命令绕开全部问题。

#### 步骤 2：ssh 密码登录板子

> **在干吗**：进板子的命令行，准备做"登记"。

```powershell
ssh radxa@<板子IP>
```

- 输入密码 → 进去后看到 `radxa@radxa-zero3:~$` 提示符；

#### 步骤 3：在板子上把公钥装进 authorized_keys（3 行）

> **在干吗**：逐行解释这三条——
>
> 1. `mkdir -p ~/.ssh`：建 `~/.ssh` 目录，`-p` 表示"已存在就别报错"（幂等）；
> 2. `cat /tmp/id_ed25519.pub >> ~/.ssh/authorized_keys`：把公钥**追加**到白名单里。**注意是 `>>` 不是 `>`**——`>` 会**清空重写**，以后再加第二台电脑的钥匙时，用错符号会把第一把删掉；
> 3. `chmod 600 ~/.ssh/authorized_keys`：把权限收紧成"只有自己可读"。**这一步不是可选的**——`sshd` 出于安全会**主动拒绝**权限过宽的密钥文件，表现为"公钥明明放进去了却还要密码"，极难查。

```bash
mkdir -p ~/.ssh
cat /tmp/id_ed25519.pub >> ~/.ssh/authorized_keys
chmod 600 ~/.ssh/authorized_keys
```

- 每行回车，**没任何输出就是成功**；

#### 步骤 4：退出板子

```bash
exit
```

### 5.5 【动手】测试免密登录

> **在干吗**：验证 5.4 登记进去的公钥真的生效了——不用密码直接进去。

回到 Windows PowerShell：

```powershell
ssh radxa@<板子IP>
```

**如果直接进 `radxa@radxa-zero3:~$`，不再要密码 → 成功。** 之后所有远程操作都从这个窗口敲命令就行。

**完成标志**：`ssh` 不提示 `radxa@<IP>'s password:` 就直接进去了。

**卡住了怎么办**：

| 现象 | 原因 | 修法 |
| --- | --- | --- |
| 仍要密码 | 公钥没进去 / 权限太宽 | 在板子上看`cat ~/.ssh/authorized_keys` 有没有那行；`ls -l ~/.ssh/authorized_keys` 是不是 `-rw-------` |
| 仍要密码，且重刷过系统 | 板子重建过 host key，Windows 记住了旧的 | `ssh-keygen -R <板子IP>` 清掉旧记录再连 |
| `Permission denied (publickey)` | 拷过去的是私钥不是公钥，或内容被截断 | 重做步骤 1，确认文件名以`.pub` 结尾 |

**为什么必须配免密 SSH**：不只是为了少打字——① 后面的 `provision` 脚本会让板子重启并自己重连，密码登录没法在重启后自动重连；② 本节之后每一个命令都要跨机器执行，每次手输密码会在几十个步骤里疯掉。

---

## 6. 板级环境配置（bring-up）：先诊断再动手

这一节把"一块能上网的 Linux 板子"变成"一块能跑机器人的板子"。

> ⚠️ **Radxa OS 和 Armbian 有差异（很重要）**：`setup-board.sh` 硬编码了启动配置文件叫 `/boot/armbianEnv.txt`（Armbian 特有）。Radxa OS 上**没有这个文件**，它用的是 `/boot/extlinux/extlinux.conf`（外加一个 `/boot/uEnv.txt`）。**先诊断再动**，别盲目跑脚本。

**本节要做三件事**：

1. **让硬件设备节点出现**——`/dev/ttyS2`（舵机总线）、`/dev/i2c-imu`（IMU）这类节点**不是插上就有**。RK3566 的每个外设控制器都要在**设备树**里被显式打开（UART2 还要选引脚复用 mux），这一步叫 **overlay（设备树叠加）**；
2. **让这些设备不被别人占着**——UART2 出厂是**内核调试串口**，内核日志会往这条线上写，而这条线正好就是舵机总线，舵机的回复会被冲掉；
3. **装上跑策略的运行时**——**ONNX Runtime**（`robotd` 加载 `.onnx` 神经网络走路要靠它）。

**为什么"先诊断"**：上面这些事在 Armbian 和 Radxa OS 上的做法不一样（配置文件不同、包名不同、overlay 目录不同）。诊断是**只读**的，零风险；先看清现状，能省掉"脚本报错 → 猜 → 乱改 → 板子开不了机"的循环。

**本节完成标志**（全部满足才进 §7）：

| 检查 | 期望 |
| --- | --- |
| `ls -l /dev/ttyS2` | 节点存在 |
| `sudo fuser -v /dev/ttyS2` | **没有任何进程占着**（有 agetty 就是没配好） |
| `ls /usr/local/lib/libonnxruntime.so*` | 存在 1.28.0 |
| `ls ~/install.sh ~/team.dev.pub` | 都在 |

### 6.1 【只读】先跑七条诊断

> **在干吗**：不改变任何东西，只问板子 7 个问题。每个问题对应后面一个"要做 / 要跳过"的决定。

```bash
# ① 启动配置文件叫什么？setup-board.sh 找的是 armbianEnv.txt
ls -la /boot/*.txt /boot/extlinux/extlinux.conf 2>/dev/null

# ② 内核版本 & 板子型号
uname -a
cat /proc/device-tree/model 2>/dev/null; echo

# ③ NetworkManager 有没有？Radxa OS 大概率已经有了
command -v nmcli && nmcli -t -f DEVICE,STATE device status

# ④ /dev/ttyS2 有没有（UART2，舵机总线）——关键检查
ls -l /dev/ttyS* /dev/ttyAMA* 2>/dev/null

# ⑤ systemctl 能跑不
systemctl --version | head -1

# ⑥ 内核启动参数里，调试控制台还挂在串口上吗？（决定要不要手动改）
cat /boot/uEnv.txt 2>/dev/null
cat /proc/cmdline

# ⑦ 舵机总线上有没有 getty 在抢（最阴的一个坑）
systemctl is-enabled serial-getty@ttyS2.service 2>/dev/null; systemctl is-active serial-getty@ttyS2.service
```

**每条在判什么**：

| 条 | 看什么 | 会决定什么 |
| -- | --- | --- |
| ① | 有`armbianEnv.txt` 还是没有 | 没有 →`setup-board.sh` 的 overlay 步会跳过，得自己动 `extlinux.conf` |
| ② | 内核版本；`model` 串**只是通用串 `Radxa ZERO 3`，不带 W/E 后缀**，别拿它认型号（见 §1） | 只作记录 |
| ③ | `nmcli` 在不在、`wlan0` 是不是它管 | 在 → §6.5 网络迁移**整节跳过** |
| ④ | `/dev/ttyS2` 在不在 | 在 → overlay 已经好了（比如已经在`rsetup` 里加过 `rk3568-uart2-m0.dtbo`） |
| ⑤ | systemd 版本 | 只作记录 |
| ⑥ | `/proc/cmdline` 里有没有 `console=ttyS0 / ttyFIQ0 / ...` | **有 → 内核日志正在污染舵机总线，必须改** |
| ⑦ | ttyS2 上有没有 getty | `active` → 必须 mask 掉（`setup-board.sh` 会做） |

> ⚠️ **⑥ 的坑**：Radxa OS 出厂把调试控制台放在 UART2（`console=ttyFIQ0,1500000n8`）。把它当舵机总线用之前，必须把 `console=` 改到屏幕（`tty1`）并**删掉 `earlycon`**——改的是 `/boot/extlinux/extlinux.conf` 里 `append` 那一行。**改完必须重启才生效。**

#### 参考实测结果（2026-09-15，可作为对照）

> 不同批次的板子出厂镜像可能不同，下面数据仅作对照，**请以自己板子上的实际输出为准**。

| 条 | 实际输出 | 意味着 |
| ---- | --- | --- |
| ① | 有`extlinux.conf` + `uEnv.txt`，**没有** `armbianEnv.txt` | 脚本 overlay 步会 warn 跳过——**这是预期行为，不是故障** |
| ② | `6.1.84-10-rk2410-nocsf` / `Radxa ZERO 3` | Radxa 的 vendor 内核；型号串不带后缀 |
| ③ | `/usr/bin/nmcli`；`wlan0:connected` | **§6.5 跳过** |
| ④ | `/dev/ttyS1` + `/dev/ttyS2` 都在 | overlay 已就绪 ✅ |
| ⑤ | `systemd 252` | 够用 |
| ⑥⑦ | 取决于`extlinux.conf` 有没有改过 / getty 有没有 mask 过 | 没改就必须补 |

### 6.2 【动手】获取脚本并放到板子上

> **在干吗**：板子是**独立的电脑**，上面没有开发机里的仓库。这一步把要在板子上执行的脚本"送过去"。
> **为什么用 `scp` 而不是让板子自己从 GitHub 下**：① 走局域网，几 MB 秒传，不受 GitHub 在国内的速度影响；② 这仓库若是**私有的**，板子上的 `curl` 会拿到 **404**（GitHub 对私有路径返回 404 而不是 401，看着像网址写错了）；③ 开发机本地本来就有这份代码。

在 Windows 主机上（假设仓库在 `<你的工作目录>\microduck`），用 PowerShell：

```powershell
cd <你的工作目录>\microduck

# 把 setup-board.sh / migrate-network.sh / install.sh + dev key 拷到板子家目录
scp scripts\setup-board.sh scripts\migrate-network.sh radxa@<板子IP>:~/
scp scripts\install.sh deploy\dev-key\team.dev.pub radxa@<板子IP>:~/
```

（`~` 表示板子的家目录 `/home/radxa`）

**这四个文件分别是干嘛的**：

| 文件 | 用途 | 本次是否用得上 |
| --- | --- | --- |
| `setup-board.sh` | §6.4 的板级 bring-up：mask getty、装 ONNX Runtime、打印体检报告 | ✅**必须** |
| `migrate-network.sh` | 把网络从 netplan 迁到 NetworkManager | ❌ 已经是 NM，用不到（拷过去无害，脚本自己会退） |
| `install.sh` | §7 装 microduck 守护进程（robotd 等） | ✅ 下一步就用 |
| `team.dev.pub` | 让这块板子成为**"开发板"**：信任团队 dev 签名，之后能装分支构建  | ✅ 建议装 |

**完成标志**：`ls -l ~/setup-board.sh ~/migrate-network.sh ~/install.sh ~/team.dev.pub` 四个文件都在。

**卡住了怎么办**：`No such file or directory` 且提示的是 **Windows 这边**的路径 → 先在 PowerShell 里 `dir scripts\setup-board.sh` 确认文件真的在（Windows 文件名不区分大小写，但 `scp` 传到 Linux 后区分）。

### 6.3 【动手】建立用户组（先于重启）

> **在干吗**：建一个系统用户组 `robot`，并把当前用户加进去。
> **为什么需要**：这套软件要让**普通用户**（`radxa`）能操作机器人（跑 `robotctl`、看日志、重启服务），但不该把用户变成 root。做法就是：设备节点和服务归 `robot` 组管，`radxa` 在组里 → 只获得精确的那几个权限。
> **为什么必须"先于重启"**：`usermod -aG` 加组**只对新的登录会话生效**——加完得重新登录 / 重启，`id` 里才会出现 `robot`。

```bash
sudo groupadd --system robot
sudo usermod -aG robot "$USER"
```

**完成标志**：现在跑 `groups` 可能还看不到 `robot`（正常）；重启后 `groups` 里出现 `robot` 才算成。
**卡住了怎么办**：`groupadd: group 'robot' already exists` → 无害，说明之前建过，继续往下。

### 6.4 【动手】运行 setup-board.sh

> **在干吗**：官方给的"板级一次性配置"脚本。它设计成**幂等**（重复跑安全）、**绝不自己重启**（需要重启时会告诉你然后停下）。
> **为什么是 `sudo sh` 而不是 `./setup-board.sh`**：它要改 `/boot` 下的启动配置、mask 系统服务、往 `/usr/local/lib` 装库——全是 root 才能做的事；而且这个镜像上的 `/tmp`、家目录挂载可能带 `noexec`，用 `sh` 显式执行最稳。
> **为什么它不删自己**：第一次跑时它会把自身复制到 `/usr/local/sbin/robot-setup-board`。因为它的工作恰恰是"改配置 → 重启 → 再确认"，而 `/tmp` 重启就没了——一个跨重启的脚本把自己删掉并不是好设计。
>
> 📖 下面这张表是"跑完看结果"用的。想彻底搞懂它内部每一步的原理、以及怎么把这套方法用在别的板子上——直接看 [§6.6](#66-setup-boardsh-逐段精读) 和 [§6.7](#67-方法论如何为新板子设计-bring-up)。

```bash
sudo sh ~/setup-board.sh
```

**它按顺序做这些事**（最后一列是它在**本教程参考板（Radxa OS）上**的实际结果）：

| 步骤 | 做什么 | 为什么 | 在参考板上的结果 |
| --- | --- | --- | --- |
| `check_environment` | 检查 root / aarch64 /`curl tar find install` 齐不齐 | 最早失败最省时间 | ✅ |
| `persist_self` | 把自己复制到`/usr/local/sbin/robot-setup-board` | 见上 | ✅ 成功 |
| `check_network` | 只读：`nmcli` 在不在、`wlan0` 归谁管 | 提醒`configd` 需要 NetworkManager | ✅ 报"已连接"，无动作 |
| `configure_overlay` | 在`armbianEnv.txt` 里设 `overlay_prefix=rk3568`、加 `overlays=uart2-m0 i2c4-imu` | 让设备树能加载，否则`/dev/ttyS2`、`/dev/i2c-imu` 都不存在 | ⚠️**warn 跳过**（找不到 `armbianEnv.txt`）。已用 `rsetup` 加过 `rk3568-uart2-m0.dtbo` / `rk3568-i2c4-m0.dtbo`，等效 |
| `free_motor_port` | mask`serial-getty@ttyS2.service`；把内核 `console=` 从串口挪到屏幕 | 别让登录终端 / 内核日志吃掉舵机回复 | ✅**mask 这半段生效且有用**；`console=` 那半段跳过（要自己改 `extlinux.conf`，见 6.1 ⑥） |
| `configure_audio` | 装`alsa-utils/device-tree-compiler/dkms/gcc/make/i2c-tools`，再装 Armbian 的 vendor 内核包 | 音频 codec 的驱动在 vendor 内核里 | ⚠️ 前半段能装成；后半段**Radxa OS 源里没有那些包 → warn `could not install the vendor kernel — audio will not work`**。**音频放弃，不影响走路** |
| `configure_tof` | 写`/dev/i2c-pihat` 的 udev 规则 | 深度传感器要固定名字 | ⚠️ 只写规则（无害），但 i2c3 总线可能没开 |
| `configure_camera` | 找`*/rockchip/overlay` 目录，装摄像头 overlay | 摄像头要开 CSI/I²S | ⚠️ Radxa OS 的 dtbo 在`/boot/dtbo/`，路径对不上 → warn 跳过 |
| `configure_imu` | 装 IMU 的 overlay | i2c4 上的 LSM6DSV16X | ⚠️ 同上 warn 跳过（i2c4 已由 rsetup overlay 开好） |
| `install_onnxruntime` | 从 GitHub 下 ONNX Runtime**1.28.0**（aarch64）装进 `/usr/local/lib` + `ldconfig` | `robotd` 靠它加载 `.onnx` 策略 | ✅**唯一真正关键的一步**。⚠️ **下载失败脚本会直接 `die` 退出**，见下表 |
| `report` | 打印 board status | 一眼看出还缺什么 | ✅ |

**预期会看到 4~6 条 warning**，全部是 Radxa OS 与 Armbian 的差异导致的**误报**，不用管。

脚本末尾会打印 **board status**。重点看：

- `motor bus /dev/ttyS2 present` → 好消息；
- `ONNX Runtime ABSENT` → 没装上，见下表；
- `wifi NetworkManager, connected` → 正常；
- 末尾 `reboot required` → 有改动要重启才生效，**重启前先确认 §0.7 的 Wi-Fi 自动连已经修好**。

**卡住了怎么办**：

| 现象 | 原因 | 修法 |
| --- | --- | --- |
| 卡在下载 ONNX Runtime / curl 报错、脚本退出 | 国内访问 GitHub releases 慢或被断 | 直接**重跑一次**（脚本幂等）；仍不行就手动装：在能上网的机器下 `onnxruntime-linux-aarch64-1.28.0.tgz`，`scp` 到板子解压，把 `lib/` 里的 `libonnxruntime.so*` 拷进 `/usr/local/lib`，再 `sudo ldconfig` |
| `could not install the vendor kernel — audio will not work` | Radxa OS 没有 Armbian 的包 | **正常，忽略**（除非要音频） |
| `no rockchip overlay directory under /boot` | Radxa OS 的 dtbo 路径不同 | **正常，忽略**（uart2/i2c4 已开好） |
| 脚本说`reboot required`，但 Wi-Fi 自动连还没修 | — | **先看 §0.7**，否则重启即失联 |

**完成标志**（就是 §6 开头那张表）：

```bash
ls -l /dev/ttyS2 /dev/i2c-imu
sudo fuser -v /dev/ttyS2          # 期望：无输出（没有任何进程占着）
ls /usr/local/lib/libonnxruntime.so*
```

### 6.5 【动手】网络迁移：netplan → NetworkManager（参考板：跳过）

> **在干吗**：Armbian 出厂用 **netplan + systemd-networkd + wpa_supplicant** 管网络；这套软件要求用 **NetworkManager**。这个脚本就是一次性迁移。
> **为什么要换（而不是"能用就行"）**：netplan 是**配置生成器**，不是网络管理器——它**没有扫描 API**，`netplan apply` 只会说"配置已应用"，不会告诉你**到底连没连上**。而手机 App 给机器人配网最需要的两件事恰好是"给我看看有哪些网络"和"这个密码错了"。NetworkManager 才有这些能力。
> **为什么这步特别标注危险**：它是**唯一能让 headless 板子直接失联**的一步——换网络栈如果出错，SSH 就永远回不来，必须接显示器键盘去救。所以它被**单独拆成一个脚本**，而不是塞在 `setup-board.sh` 里。

**本教程参考板：跳过本节。**

理由（§6.1 ③ 的实测）：`nmcli` 存在、`wlan0:connected`——这块 Radxa OS 出厂就是 NetworkManager，没什么可迁的。

> 如果以后换回 Armbian 镜像，则要跑（模式是"**重启前后各跑一次**"）：
>
> ```bash
> sudo sh ~/migrate-network.sh
> sudo reboot
> # 重启后 SSH 回来，再跑一次，用来撤销兜底配置
> sudo /usr/local/sbin/robot-migrate-network
> ```
>
> 它是"重启前后各跑一次"的两段式：第一次改配置并留下一个**兜底**（万一网络没起来就自动回滚），重启后再跑一次**退掉兜底**。

### 6.6 【原理】setup-board.sh 逐段精读

> **这一节不讲"敲什么命令"，只讲"脚本里到底发生了什么、为什么这么设计"。**读完之后，换一块新板子（甚至换一款机器人），也能自己把 bring-up 流程设计出来。

#### 6.6.0 先看它的设计原则

脚本 `scripts/setup-board.sh` 开头几乎没有代码，全是注释在争论"为什么"。那些争论就是它的设计原则——**理解了这 6 条，整份脚本就没有黑箱了**：

| # | 原则 | 具体做法 | 为什么必须这样 |
| - | --- | --- | --- |
| 1 | **只管"板子"，不管"软件"** | 它和`install.sh` 是**两个**脚本 | 见下面单独展开 |
| 2 | **幂等**（重复跑安全） | 每一步都是"**先检查，再决定改不改**"，绝不直接写 | 它自己的工作就是"改配置 → 重启 → 再确认"，**必然要跑第二遍**；不幂等的话第二遍会毁掉第一遍的成果 |
| 3 | **绝不自作主张重启** | 只设一个变量`needs_reboot=1`，最后打印"该重启了"然后**自己结束** | 重启会瞬间切断 SSH。脚本**没有资格**替操作者决定让板子失联——这个决定必须由拿着板子的人做 |
| 4 | **先把自己存下来** | `persist_self`：复制自己到 `/usr/local/sbin/robot-setup-board` | `/tmp` **不跨重启**。一个"改启动配置 → 重启 → 再确认"的脚本，重启后把自己删掉会让流程断掉 |
| 5 | **非核心功能一律"软失败"** | 音频 / 摄像头 / ToF / 蓝牙全部"出错就`warn` 然后继续"；只有电机总线是硬需求 | **能走路的板子 > 样样完美的板子。**没有音频的鸭子走得和好的一模一样，所以音频**不允许**中断 provisioning |
| 6 | **只打印命令，不替你执行** | `fetch_cmd` 只 `printf` 一行 `curl` 命令给你看 | ① 脚本自己只从**公开**地址下一样东西（ONNX Runtime），不需要 token；② 打印的 token 写成 `$DUCK_TOKEN` **变量名**而不是值——因为 **bring-up 日志会被贴进聊天 / issue**，泄露的 token 得挨个板子轮换 |

**第 1 条展开看（这是整份架构最重要的一刀）**：

| | `setup-board.sh` | `install.sh` |
| --- | --- | --- |
| 管什么 | 操作系统层 bring-up：设备树 overlay、ONNX Runtime | 装一个**签名**的守护进程 release |
| 属于谁 | **板子** | **软件** |
| 多久变一次 | 极少变 | **每次更新都装** |
| 要重启吗 | 要（overlay 要重启才生效） | 不要 |
| 需要 root  | 是 | 是 |
| 高风险操作 | 有（改启动配置） | 有（改网络栈是单独脚本） |

> **如果不拆开会怎样**：每次软件更新都要重新讨论一遍启动配置。overlay、内核 console 这些**和软件版本毫无关系**的东西，会被卷进"更新"里反复处理。**"频率不同、生命周期不同、风险不同"的东西，就该是两个脚本。**

#### 6.6.1 先读 main()：调用顺序就是整个流程

```sh
main() {
    check_environment        # ① 是不是 root / aarch64 / 工具齐不齐
    persist_self             # ② 把自己复制到 /usr/local/sbin（跨重启）
    configure_overlay        # ③ 打开 UART2（舵机总线）+ i2c4（IMU）的设备树开关
    check_network            # ④ 只读：Wi-Fi 归谁管
    free_motor_port          # ⑤ 把登录终端和内核 console 从舵机串口上赶走
    configure_bluetooth      # ⑥ 手柄配对需要的 BlueZ 设置（默认什么都不动）
    configure_audio          # ⑦ 音频 codec：5 层，可失败，顺带装 vendor 内核
    configure_tof            # ⑧ 头部深度传感器的稳定设备名
    configure_camera "${vendor_ver:-}"   # ⑨ 摄像头 overlay（要 ⑦ 装的 vendor 内核）
    configure_imu    "${vendor_ver:-}"   # ⑩ IMU overlay + 稳定设备名（同样要 ⑦）
    install_onnxruntime      # ⑪ 跑走路策略的运行时
    report                   # ⑫ 体检报告（只读）
}
```

**这个顺序不是随便排的，有两处硬依赖**：

- **⑦ 必须在 ⑨ 之前**——音频那步会装 **Armbian vendor 内核**，而摄像头的 MIPI-CSI 采集驱动和 overlay 目录（`/boot/dtb-<ver>/rockchip/overlay`）**只存在于 vendor 内核那个分支**。所以 ⑨⑩ 要拿 ⑦ 算出来的 `vendor_ver`。这就是 `configure_camera "${vendor_ver:-}"` 那个参数的意义。
- **③ 必须在 ⑤ 之前**，而且 ③ 和 ⑤ 都改同一个文件（`armbianEnv.txt`），但改的是**不同变量**（overlay 相关 vs `console=`）——分开写是为了两份逻辑互不干扰。
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

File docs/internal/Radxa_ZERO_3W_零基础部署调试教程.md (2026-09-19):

# Radxa ZERO 3W 零基础部署与调试教程

> **本教程已踩过坑、验证过可行**（2026-09-15 实战更新），针对你的实际硬件：
> **Radxa ZERO 3W / RK3566 / 2GB LPDDR4 / 无 eMMC**，开发主机为 **Windows + PowerShell**。
> 目标：把一块"刚拆封、什么都不会"的空白板子，变成可以登录、可以跑机器人控制软件、知道怎么排障的开发板。
>
> 内容依据 `E:\optiDuck\joyandai\microduck` 的官方文档（`docs/onboarding.md`、`docs/robot/install-dev.md`、`docs/robot/cheatsheet.md`、`docs/robot/install-by-hand.md`、`deploy/README.md`）+ `E:\optiDuck\OpenMicroDuck\docs` 硬件文档 + 2026-09-15 实战踩坑经验。

## 怎么读这份教程

每一步都按同一套四问写清楚，你可以只看你需要的那一问：

| 标记 | 含义 |
| --- | --- |
| **在干吗** | 这条命令 / 这个动作，在系统里到底发生了什么（不是"照着敲"，而是知道它在动什么） |
| **为什么必须做** | 不做会怎样；以及为什么是这个做法而不是别的做法 |
| **完成标志** | 怎么算成功 —— 用可观察的输出判断，不靠"感觉应该行" |
| **卡住了怎么办** | 这一步最常见的失败长相 + 往哪查 |

同时标注每个步骤的性质：

- **【动手】** = 会改变板子/卡的状态，敲下去就有后果；
- **【只读】** = 纯查看，不改任何东西，放心跑；
- **⚠️** = 已知会失败、或者是坑的地方（在你这块 Radxa OS 上尤其要注意）。

> 通读建议：第一次做，**按 §2 → §13 的顺序**；出问题直接跳 §0（踩坑史）和 §11（速查表）；想搞懂"为什么每一步长这样"，看 §6.6 / §6.7（现象 → 原理）和 **§10（拆箱总纲：剩下所有黑箱 + 通用拆解方法）**。

---

## 🚨 0. 先看：踩坑血泪史（必看！帮你节省 2~3 小时）

> **这是你之前 initramfs 卡了整整一个下午的真实原因**，按影响程度排序：

### 0.1 电源不够 → 板内核能起来、但 **TF 卡物理设备都识别不到**

- **症状**：板子亮、HDMI 有输出、内核起来了，但 initramfs 里 `ls /dev/mmcblk*` 报 `No such file or directory`；
- **根因**：你旧手机的 5V/1A 充电头 + 细 Type-C 线，电流不够，RK3566 的 SDIO 控制器起不来；
- **修法**：换一个 **5V/2A 或 3A** 的充电头 + **粗一点的 Type-C 线**（比如小米 90W PD 快充头 + 5A 粗线，亲测解决）。**电压必须是 5V（Type-C 默认），不会烧板子，放心用大电流**。
- **验证**：换电源后重上电，`blkid` 应该能看到 `/dev/mmcblk1`（Radxa ZERO 3W 无 eMMC，SD 卡走 mmcblk1；有 eMMC 的板子 SD 卡走 mmcblk0）。

### 0.2 Windows 上烧 Armbian 镜像的已知 bug → 分区表被清掉

- **症状**：Armbian imager 校验显示"写入成功"，但板子启动后 initramfs 里 `blkid` 只看到 `/dev/mmcblk1: PTUUID=... PTTYPE="gpt"`（**空 GPT 分区表**——只有一张分区"目录"，实际 p1/p2 分区内容全丢了）；
- **根因**：Windows 上的 Armbian imager / Etcher / Rufus 在写入后会被 Windows 的 **分区管理安全机制** 干扰——Windows 看到一个带 GPT 头但没有有效分区的磁盘时，可能自动重新生成一张空 GPT，把镜像实际写入的分区内容覆盖掉；
- **修法**（三选一，按推荐顺序）：
  1. **换 Radxa OS 官方镜像 + balenaEtcher 烧录**（本教程推荐，已验证成功，见 §3）；
  2. 实在要用 Armbian → 用 **Win32 Disk Imager** 或 **WSL 里的 `dd`**（直接操作块设备扇区，绕过 Windows 分区管理）；
  3. 烧完后**立刻弹出 TF 卡，绝对不要在 Windows 上点任何"格式化"、"修复驱动器"、"扫描"弹窗**。

### 0.3 Armbian 的设备树里只有通用 `radxa-zero3`，没有 ZERO 3W 专用 dtb

- **症状**：板子能启动但 Wi-Fi 不工作 / eMMC 不识别 / 某些 GPIO 控制器找不到；
- **根因**：Armbian 26.8.1 的 vendor 内核（6.1.115）**只 ship 了 `rk3566-radxa-zero3.dtb`，没有 3W 专用的 `rk3566-radxa-zero-3w.dtb`**——3W 有 Wi-Fi/BT 模块（aic8800），占用 SDMMC1 控制器，设备树必须包含对应的 pinctrl/regulator 配置；
- **修法**：直接用 **Radxa OS 官方镜像**（它自己维护设备树，自动识别 ZERO 3W / 3E），绕开这个问题。

### 0.4 Windows PowerShell 的 `$env:USERPROFILE` 展开坑

- **症状**：教程里写的

  ```
  type $env:USERPROFILE\.ssh\id_ed25519.pub | ssh user@ip "cat >> ~/.ssh/authorized_keys"
  ```

  报 `Get-Content : 无法将参数绑定到"Path"，因为该参数是空值`；
- **根因**：PowerShell 管道 + 环境变量展开 + 中文路径（你的用户名是"刘"）这三个因素的组合 bug；
- **修法**：**不用管道**，改用 `scp` 直接把公钥文件拷到板子，再在板子上手动合并（见 §5.2）。

### 0.5 SSH 连不上 Connection refused → 板子上没装 openssh-server

- **症状**：板子能 ping 通、IP 正确、但 `ssh` 报 `Connection refused`；
- **根因**：Radxa OS 出厂**没装 openssh-server**（或装了但没启动）；
- **修法**：在板子的本地终端（HDMI+键盘）跑 `sudo apt install -y openssh-server && sudo systemctl enable --now ssh`。

### 0.6 initramfs 里 `ls /dev/mmcblk*` 两种情况的硬核区别

| 情况 | `ls /dev/mmcblk*` 输出 | 根因 |
| --- | --- | --- |
| ❌ 卡完全没读到 | `No such file or directory` | 电源不够！换 90W 头 / 粗线 |
| ⚠️ 卡读到但空分区 | `/dev/mmcblk1` 存在，但 `blkid` 只有 `PTUUID=... PTTYPE=gpt`（没 p1/p2） | 烧录被 Windows 干扰了，换 Radxa OS + Etcher 重烧 |
| ✅ 正常 | `/dev/mmcblk1p1` + `/dev/mmcblk1p2` 都有，`blkid` 输出带 `UUID=` 和 `TYPE=` | 烧录正确，UUID 对得上 cmdline.txt 就能启动 |

### 0.7 重启后 Wi-Fi 不自动连 → 开机 SSH 失联（密码被存进"用户密钥环"）

- **症状**：在桌面/终端里手动连上 Wi-Fi 后一切正常，但**重启后板子不联网、SSH 连不上**；接上显示器，只要**选账户输一次密码登录**，Wi-Fi 立刻自己就通了 —— 看着像"必须先登录才行"，其实是**密码取不到**；
- **根因**：这个 Wi-Fi 连接的密码（PSK）是**以用户身份**保存的：Keyfile 里写着 `psk-flags=1`（agent-owned），**文件里根本没有 `psk=` 这一行**。NetworkManager 开机时以 root 身份运行，取密码要靠桌面会话里的 `secret agent`；而你屏蔽 sddm（图形登录）之后，开机**没有任何用户会话 → 没有 agent → 直接判失败**：

  ```
  (wifi) access point '天问412' has security, but secrets are required.
  no secrets: No agents were available for this request.
  state change: need-auth -> failed (reason 'no-secrets')
  Activation: failed for connection '天问412'
  ```
- **一眼确诊**（在还能连上的时候跑）：

  ```bash
  sudo grep -n -E "psk-flags|^psk=" /etc/NetworkManager/system-connections/*.nmconnection
  ```

  看到 `psk-flags=1` 且**没有** `psk=` → 就是这个坑；
- **修法**（一条命令，把密码改成"系统所有"，开机不需要任何会话）：

  ```bash
  # 自动取 UUID，避免手输中文 SSID 踩 IME 坑
  UUID=$(nmcli -t -f UUID,TYPE connection show | awk -F: '$2=="802-11-wireless"{print $1; exit}')
  echo "$UUID"

  sudo nmcli connection modify "$UUID" wifi-sec.psk "<你的WiFi密码>" wifi-sec.psk-flags 0
  # 顺手把持久化属性一次配齐
  sudo nmcli connection modify "$UUID" \
    connection.autoconnect yes \
    connection.autoconnect-priority 100 \
    connection.autoconnect-retries -1 \
    802-11-wireless.powersave 2

  sudo reboot
  ```

  **验收**：重启后**不接显示器、不做任何登录**，等 90 秒直接
  ```powershell
  ssh radxa@<板子IP>
  ```

  能直接进 = 修好了（显示器上仍旧停在 `login:` 属于正常，与联网无关）；
- **两个小坑**：

  1. `nmcli connection modify` 设置时可以用别名 `wifi-sec.psk-flags`，但 `nmcli -f` **查询字段必须写全名** `802-11-wireless-security.psk-flags`，否则报 `invalid field`；
  2. 改完密码会**明文**存在 `/etc/NetworkManager/system-connections/*.nmconnection`（权限 `600`，仅 root 可读）——这是 NetworkManager 的标准做法，不是配置错误；
- **不需要排查的方向**（别浪费时间）：`wpa_supplicant` 是 active **属于正常**（Debian 上 NetworkManager 通过 D-Bus 调它做 WPA 握手），不是"抢占网卡"；`systemd-networkd` 应该 inactive。

---

## 1. 先搞清楚：这块板子在你项目里是干什么的

> **型号先确认清楚（别再纠结了）**：Radxa 官方**没有**一块叫 "ZERO 3" 的板子 —— **"ZERO 3" 只是这一代的系列名 / 文档目录名**，实际在售的只有两个型号：
>
> |                   | Radxa**ZERO 3W**                           | Radxa**ZERO 3E**                |
> | ----------------- | ------------------------------------------------ | ------------------------------------- |
> | 无线              | ✅ Wi-Fi 6 + BT 5.4（AIC8800D80）                | ❌ 没有                               |
> | 有线              | ❌ 没有网口                                      | ✅ 千兆以太网（支持 PoE，需另配 HAT） |
> | 存储              | 板载 eMMC**0**/8/16/32/64GB 可选 + microSD | 只有 microSD                          |
> | SoC / 内存 / 尺寸 | RK3566 / LPDDR4 1~8GB / 65×30mm                 | 与 3W 相同                            |
>
> **你的板子 = ZERO 3W（eMMC 0GB 的 SKU）**：Wi-Fi 能连 + 没有 eMMC + 没有网口，三条特征全中，只可能是 3W。所谓"无 eMMC"不是另一个型号，而是 3W 的存储选配（0GB）。
>
> 被绕晕的来源：镜像名 `radxa-zero3_bookworm_kde_b1`、主机名 `radxa-zero3`、文档目录 `/zero/zero3/` —— **两个型号共用这套命名**，到处写着 "zero3"，但它不代表型号。
>
> 想自己再确认一次 —— **注意 `/proc/device-tree/model` 在 3W 和 3E 上都只打印通用的 `Radxa ZERO 3`，不带 W/E 后缀**（2026-09-15 在真机上验证过），所以别靠它区分型号：
>
> ```bash
> ls /sys/class/net/                      # 有 wlan0 → 3W；有 eth0 → 3E（3E 无无线，3W 无网口）
> ls /dev/mmcblk*                         # 只有 mmcblk1 → 无 eMMC；另有 mmcblk0/mmcblk2 → 有 eMMC
> cat /proc/device-tree/model; echo       # 只会打印通用串 "Radxa ZERO 3"
> ```

Radxa ZERO 3W 是鸭子的**"大脑/主控"**。整台 Microduck（约 25 cm、800g 的双足小鸭）由它负责：

- 跑一个 **50 Hz 控制回路**，读 15 个舵机 + 机身 IMU，组 61 维观测，用 ONNX 神经网络（强化学习策略）推理，输出 14 个关节目标，驱动舵机走路/站立/踢球/翻滚/起身；
- 一组 Rust 守护进程：`robotd`（控制/电机）、`configd`（Wi-Fi/名字/PIN）、`updaterd`（签名更新/回滚）、`btd`（蓝牙门面）、`padd`（手柄）、`mediad`（相机/推流）、`tofd`（头部深度传感器）；
- 板载 Wi-Fi + 蓝牙：手机 App（BLE）、游戏手柄、远程 WebRTC 都走这里。

**关键概念（先记住这三个，后面都好懂）：**

1. **走路策略在 CPU 上跑 ONNX Runtime（ORT），不在 NPU 上。** NPU 是给"视觉/鸭子检测"预留的，且默认是关的。所以"2GB RAM、无 eMMC"对走路这一关没有任何影响——官方那档甚至只有 1GB RAM。
2. **只有 `robotd` 能碰电机。** 其它进程（手柄、手机、脚本）发的都是"意图"，由 `robotd` 内部的安全层决定是否执行。
3. **更新 = 整目录替换 + 验签 + 健康门 + 自动回滚。** 装坏了自己会滚回去，不是打补丁。

> 你这块 2GB 内存比官方 1GB 还多，只会更充裕。**无 eMMC 不是缺陷**：意味着你从 microSD 卡启动（对零基础反而更简单，不需要进入 USB 烧录的 maskrom 模式），只是存储介质换成卡。

---
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

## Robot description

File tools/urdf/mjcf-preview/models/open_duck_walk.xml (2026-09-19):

<?xml version="1.0" ?>
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
<mujoco model="open_duck">
  <compiler angle="radian" meshdir="open_duck_assets"/>
  <default>
    <default class="microduck">
      <joint frictionloss="0.1" armature="0.005"/>
      <position kp="50" dampratio="1"/>
      <default class="visual">
        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
      </default>
      <default class="collision">
        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
      </default>
    </default>
    <default class="chosen_actuator">
      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
      <joint damping="0.053" frictionloss="0.0048" armature="0.0018"/>
      <position kp="0.55" kv="0.0" forcerange="-0.96 0.96" ctrlrange="-10.0 10.0"/>
    </default>
    <default class="passive_joint">
      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
      <joint damping="0.0" frictionloss="0.0" armature="0.0001"/>
    </default>
  </default>
  <worldbody>
    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
    <body name="trunk_base" pos="-0.107580602 -0.0236402502 0.122202068" quat="-0.2071533 0.124947992 0.586534625 0.772950608" childclass="microduck">
      <freejoint name="trunk_base_freejoint"/>
      <inertial pos="-0.18015 0.033489 -0.15391" mass="0.22976" fullinertia="0.00010163802 0.000100057687 0.000134452293 7.1745122e-06 2.17528969e-05 4.00690091e-09"/>
      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
      <body name="yaw2roll" pos="-0.16159 0.11336 0.045113" quat="0.781252752 -0.572448525 0.193294375 -0.156793204">
        <joint name="left_hip_yaw" type="hinge" axis="3.00000143e-06 -0.00974900465 0.999952477" range="-0.4363 0.5236" class="chosen_actuator"/>
      <inertial pos="0.00091469 -0.0010233 -0.026724" mass="0.056714" fullinertia="1.5934e-05 1.7142e-05 1.0886e-05 -3.9602e-07 1.4998e-07 4.4779e-08"/>
        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
      <body name="hip_l" pos="0.019835 0.005922 -0.01708" quat="-0.119107122 0.697003776 0.119109263 0.697002305">
        <joint name="left_hip_roll" type="hinge" axis="-1.64249879e-16 -2.80577213e-17 -1" range="-0.384 0.384" class="chosen_actuator"/>
      <inertial pos="-0.0029859 0.017816 -0.0048704" mass="0.010639" fullinertia="3.6547e-06 2.1813e-06 2.1957e-06 2.5081e-07 -1.8375e-07 1.1069e-06"/>
        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
      <body name="upper_leg_left" pos="-0.0055981 0.033536 -0.025" quat="0.670587578 -0.624507752 -0.331649413 -0.224301214">
        <joint name="left_hip_pitch" type="hinge" axis="-2.17659221e-16 3.1992946e-17 -1" range="-1.5708 1.5708" class="chosen_actuator"/>
      <inertial pos="-0.023024 -0.025162 0.018536" mass="0.083426" fullinertia="1.7785e-05 1.7915e-05 1.8334e-05 -1.0982e-07 2.3293e-21 -3.3881e-21"/>
        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
      <body name="leg" pos="-0.030542 -0.052752 -6.9388939e-18" quat="3.65194017e-06 0.994210795 -0.107447174 -3.94675508e-07">
        <joint name="left_knee" type="hinge" axis="-5.03343828e-17 -1.62641156e-16 -1" range="-1.5708 1.5708" class="chosen_actuator"/>
      <inertial pos="-0.023773 0.032093 -0.013313" mass="0.045494" fullinertia="1.0572e-05 8.4609e-06 1.0335e-05 2.6958e-06 3.9069e-09 -5.7257e-09"/>
        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
      <body name="ankle_left" pos="-0.030042 0.044027 0.0048" quat="0.107438551 1.07686056e-17 4.96619075e-17 0.994211727">
        <joint name="left_ankle" type="hinge" axis="9.11783024e-17 2.26968502e-16 1" range="-1.5708 1.5708" class="chosen_actuator"/>
      <inertial pos="0.0061372 -0.011792 -0.0195" mass="0.023715" fullinertia="7.1898e-06 7.0883e-06 5.0577e-06 -1.7453e-06 -3.4411e-21 4.2352e-21"/>
        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
      </body>
      </body>
      </body>
      </body>
      </body>
      <body name="neck" pos="-0.11753 0.16438 0.017486" quat="0.987909697 0.149777852 -0.00599783679 -0.0395607299">
        <joint name="neck_pitch" type="hinge" axis="-3.85470055e-17 4.77018285e-17 -1" range="-1.5708 1.0472" class="chosen_actuator"/>
      <inertial pos="0.0060253 0.038279 0.019629" mass="0.085354" fullinertia="2.2401e-05 1.3363e-05 1.8394e-05 -1.4588e-06 -1.6411e-21 2.7529e-21"/>
        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
      <body name="neck_pitch" pos="0.012051 0.076557 0.000255" quat="1.34924298e-11 3.6732051e-06 1 3.6732051e-06">
        <joint name="head_pitch" type="hinge" axis="-1.52062968e-17 2.90407261e-17 1" range="-1.5708 1.5708" class="chosen_actuator"/>
      <inertial pos="-0.0063834 0.013031 -0.019" mass="0.0061001" fullinertia="1.8453e-06 1.675e-06 6.6543e-07 1.0975e-07 1.4558e-22 -1.5882e-22"/>
        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
      <body name="yaw_roll_motion" pos="-0.010388 0.021207 -0.019" quat="0.698084563 -0.676440123 -0.205986844 0.112588288">
        <joint name="head_yaw" type="hinge" axis="-4.71379409e-18 -8.27514369e-17 1" range="-2.9671 2.9671" class="chosen_actuator"/>
      <inertial pos="-0.002532 0.0088067 0.019573" mass="0.051243" fullinertia="1.4551e-05 9.3889e-06 1.3564e-05 1.0047e-06 1.1087e-07 -3.5674e-07"/>
        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
      <body name="jaw_soft" pos="0.018587 0.00099513 0.01774" quat="0.690317308 0.038552222 0.706055395 0.153171535">
        <joint name="head_roll" type="hinge" axis="-1.06026126e-16 1.80019017e-17 1" range="-0.4363 0.4363" class="chosen_actuator"/>
      <inertial pos="-0.0053623 0.0068753 -0.00017064" mass="0.11741" fullinertia="0.00016779 0.00013205 0.00011434 -1.2997e-05 -7.2514e-06 1.9677e-06"/>
        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
      </body>
      </body>
      </body>
      </body>
      <body name="bearing_roll" pos="-0.16049 0.1271 0.00070269" quat="0.583592001 0.76967868 -0.206280658 -0.156407791">
        <joint name="right_hip_yaw" type="hinge" axis="0.333667217 0.424713119 -0.84159667" range="-0.5236 0.4363" class="chosen_actuator"/>
      <inertial pos="0.00085255 0.0010756 0.026724" mass="0.056714" fullinertia="1.5891e-05 1.7184e-05 1.0886e-05 3.219e-07 -1.5237e-07 3.5828e-08"/>
        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
      <body name="hip_l_2" pos="0.019176 -0.004514 0.017052" quat="0.684125165 -0.0174977661 0.706890611 -0.17880786">
        <joint name="right_hip_roll" type="hinge" axis="0.00101227193 -0.0269519053 0.999636219" range="-0.384 0.384" class="chosen_actuator"/>
      <inertial pos="0.0018905 -0.017966 -0.0038705" mass="0.010639" fullinertia="3.6793e-06 2.1567e-06 2.1957e-06 1.6133e-07 1.1742e-07 -1.1159e-06"/>
        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
      <body name="upper_leg_right" pos="0.0035607 -0.033813 -0.024" quat="0.189518345 0.116592529 0.697429456 -0.681235006">
        <joint name="right_hip_pitch" type="hinge" axis="0.205420137 -0.666297282 -0.716833662" range="-1.5708 1.5708" class="chosen_actuator"/>
      <inertial pos="0.030473 -0.009603 0.018536" mass="0.083426" fullinertia="1.7723e-05 1.7977e-05 1.8334e-05 6.5877e-09 -8.4703e-22 -2.1176e-22"/>
        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
      <body name="leg_2" pos="0.051881 -0.031999 -6.9388939e-18" quat="1.34924449e-11 -3.6732051e-06 1 -3.6732051e-06">
        <joint name="right_knee" type="hinge" axis="0.277448135 0.630719764 -0.724717263" range="-1.5708 1.5708" class="chosen_actuator"/>
      <inertial pos="-0.034959 -0.019313 -0.013313" mass="0.045494" fullinertia="7.7902e-06 1.1243e-05 1.0335e-05 -2.324e-06 6.1928e-09 3.1142e-09"/>
        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
      <body name="ankle_right" pos="-0.047618 -0.023946 0.00445" quat="1 0 0 0">
        <joint name="right_ankle" type="hinge" axis="-0.277458004 0.630718341 0.724714723" range="-1.5708 1.5708" class="chosen_actuator"/>
      <inertial pos="-0.0092602 -0.0095372 -0.0195" mass="0.023715" fullinertia="8.1401e-06 6.1379e-06 5.0577e-06 1.4305e-06 2.647e-22 0"/>
        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
      </body>
      </body>
      </body>
      </body>
      </body>
    </body>
  </worldbody>
  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
  <sensor>
    <framequat name="orientation" objtype="site" noise="0.001" objname="imu"/>
    <gyro name="angular-velocity" site="imu" noise="0.005"/>
    <gyro name="imu_ang_vel" site="imu"/>
    <velocimeter name="imu_lin_vel" site="imu"/>
    <accelerometer name="imu_accel" site="imu"/>
    <subtreeangmom name="root_angmom" body="trunk_base"/>
  </sensor>
  <actuator>
    <position class="chosen_actuator" name="left_hip_yaw" joint="left_hip_yaw"/>
    <position class="chosen_actuator" name="left_hip_roll" joint="left_hip_roll"/>
    <position class="chosen_actuator" name="left_hip_pitch" joint="left_hip_pitch"/>
    <position class="chosen_actuator" name="left_knee" joint="left_knee"/>
    <position class="chosen_actuator" name="left_ankle" joint="left_ankle"/>
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

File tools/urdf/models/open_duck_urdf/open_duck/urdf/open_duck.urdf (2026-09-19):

<?xml version="1.0" encoding="utf-8"?>
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
<robot name="open_duck">
  <link name="base_link">
    <inertial>
      <origin xyz="-0.18015 0.033489 -0.15391" rpy="0 0 0" />
      <mass value="0.22976" />
      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
    </inertial>
    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
  </link>
  <link name="yaw2roll">
    <inertial>
      <origin xyz="0.00091469 -0.0010233 -0.026724" rpy="0 0 0" />
      <mass value="0.056714" />
      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
    </inertial>
    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
  </link>
  <joint name="left_hip_yaw" type="revolute">
    <origin xyz="-0.16159 0.11336 0.045113" rpy="-1.2954 0.12282 -0.4891" />
    <parent link="base_link" />
    <child link="yaw2roll" />
    <axis xyz="3e-06 -0.009749 0.999952" />
    <limit lower="-0.4363" upper="0.5236" effort="1.5" velocity="3.0" />
  </joint>
  <link name="hip_l">
    <inertial>
      <origin xyz="-0.0029859 0.017816 -0.0048704" rpy="0 0 0" />
      <mass value="0.010639" />
      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
    </inertial>
    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
  </link>
  <joint name="left_hip_roll" type="revolute">
    <origin xyz="0.019835 0.005922 -0.01708" rpy="-0.79989 -1.5708 -2.0032" />
    <parent link="yaw2roll" />
    <child link="hip_l" />
    <axis xyz="0 0 -1" />
    <limit lower="-0.384" upper="0.384" effort="1.5" velocity="3.0" />
  </joint>
  <link name="upper_leg_left">
    <inertial>
      <origin xyz="-0.023024 -0.025162 0.018536" rpy="0 0 0" />
      <mass value="0.083426" />
      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
    </inertial>
    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
  </link>
  <joint name="left_hip_pitch" type="revolute">
    <origin xyz="-0.0055981 0.033536 -0.025" rpy="-1.5708 -0.81097 0.1654" />
    <parent link="hip_l" />
    <child link="upper_leg_left" />
    <axis xyz="0 0 -1" />
    <limit lower="-1.5708" upper="1.5708" effort="1.5" velocity="3.0" />
  </joint>
  <link name="leg">
    <inertial>
      <origin xyz="-0.023773 0.032093 -0.013313" rpy="0 0 0" />
      <mass value="0.045494" />
      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
    </inertial>
    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
  </link>
  <joint name="left_knee" type="revolute">
    <origin xyz="-0.030542 -0.052752 0" rpy="-3.1416 0 -0.21531" />
    <parent link="upper_leg_left" />
    <child link="leg" />
    <axis xyz="0 0 -1" />
    <limit lower="-1.5708" upper="1.5708" effort="1.5" velocity="3.0" />
  </joint>
  <link name="ankle_left">
    <inertial>
      <origin xyz="0.0061372 -0.011792 -0.0195" rpy="0 0 0" />
      <mass value="0.023715" />
      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
    </inertial>
    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
  </link>
  <joint name="left_ankle" type="revolute">
    <origin xyz="-0.030042 0.044027 0.0048" rpy="0 0 2.9263" />
    <parent link="leg" />
    <child link="ankle_left" />
    <axis xyz="0 0 1" />
    <limit lower="-1.5708" upper="1.5708" effort="1.5" velocity="3.0" />
  </joint>
  <link name="bearing_roll">
    <inertial>
      <origin xyz="0.00085255 0.0010756 0.026724" rpy="0 0 0" />
      <mass value="0.056714" />
      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
    </inertial>
    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
  </link>
  <joint name="right_hip_yaw" type="revolute">
    <origin xyz="-0.16049 0.1271 0.00070269" rpy="1.8441 0 -0.52371" />
    <parent link="base_link" />
    <child link="bearing_roll" />
    <axis xyz="0 0 -1" />
    <limit lower="-0.5236" upper="0.4363" effort="1.5" velocity="3.0" />
  </joint>
  <link name="hip_l_2">
    <inertial>
      <origin xyz="0.0018905 -0.017966 -0.0038705" rpy="0 0 0" />
      <mass value="0.010639" />
      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
    </inertial>
    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
  </link>
  <joint name="right_hip_roll" type="revolute">
    <origin xyz="0.019176 -0.004514 0.017052" rpy="-1.5708 1.2904 -1.8017" />
    <parent link="bearing_roll" />
    <child link="hip_l_2" />
    <axis xyz="0 0 -1" />
    <limit lower="-0.384" upper="0.384" effort="1.5" velocity="3.0" />
  </joint>
  <link name="upper_leg_right">
    <inertial>
      <origin xyz="0.030473 -0.009603 0.018536" rpy="0 0 0" />
      <mass value="0.083426" />
      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
    </inertial>
    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
  </link>
  <joint name="right_hip_pitch" type="revolute">
    <origin xyz="0.0035607 -0.033813 -0.024" rpy="-1.5708 0.43698 -3.0359" />
    <parent link="hip_l_2" />
    <child link="upper_leg_right" />
    <axis xyz="0 0 -1" />
    <limit lower="-1.5708" upper="1.5708" effort="1.5" velocity="3.0" />
  </joint>
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

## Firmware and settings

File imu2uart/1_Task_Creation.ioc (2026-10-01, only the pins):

Mcu.UserName=STM32F411CEUx
PA10.Signal=USART1_RX
PA13.Signal=SYS_JTMS-SWDIO
PA14.Signal=SYS_JTCK-SWCLK
PA9.Signal=USART1_TX
PB6.Signal=I2C1_SCL
PB7.Signal=I2C1_SDA
PC14-OSC32_IN.Signal=RCC_OSC32_IN
PC15-OSC32_OUT.Signal=RCC_OSC32_OUT

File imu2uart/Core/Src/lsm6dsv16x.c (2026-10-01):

/**
  ******************************************************************************
  * @file    lsm6dsv16x.c
  * @brief   I2C driver for the ST LSM6DSV16X IMU.
  *
  * The configuration follows DS13510 Rev 4:
  *   - accelerometer: 240 Hz, high-performance mode, +/-2 g, LPF2 enabled
  *   - gyroscope:     240 Hz, high-performance mode, +/-250 dps, LPF1 enabled
  *   - BDU and automatic register address increment enabled
  *   - SFLP (in-chip sensor fusion): game rotation vector, 120 Hz, into the FIFO
  ******************************************************************************
  */

#include "lsm6dsv16x.h"

#include <math.h>
#include <string.h>

#define LSM6DSV16X_REG_FUNC_CFG_ACCESS   0x01U
#define LSM6DSV16X_REG_EMB_FUNC_EN_A     0x04U
#define LSM6DSV16X_REG_FIFO_CTRL3        0x09U
#define LSM6DSV16X_REG_FIFO_CTRL4        0x0AU
#define LSM6DSV16X_REG_WHO_AM_I          0x0FU
#define LSM6DSV16X_REG_CTRL1             0x10U
#define LSM6DSV16X_REG_CTRL2             0x11U
#define LSM6DSV16X_REG_CTRL3             0x12U
#define LSM6DSV16X_REG_CTRL6             0x15U
#define LSM6DSV16X_REG_CTRL7             0x16U
#define LSM6DSV16X_REG_CTRL8             0x17U
#define LSM6DSV16X_REG_CTRL9             0x18U
#define LSM6DSV16X_REG_FIFO_STATUS1      0x1BU
#define LSM6DSV16X_REG_STATUS            0x1EU
#define LSM6DSV16X_REG_OUTX_L_G          0x22U
#define LSM6DSV16X_REG_EMB_FUNC_FIFO_EN_A 0x44U
#define LSM6DSV16X_REG_SFLP_ODR          0x5EU
#define LSM6DSV16X_REG_FIFO_DATA_OUT_TAG 0x78U

#define LSM6DSV16X_CTRL3_SW_RESET        0x01U
#define LSM6DSV16X_CTRL3_IF_INC          0x04U
#define LSM6DSV16X_CTRL3_BDU             0x40U
#define LSM6DSV16X_CTRL3_BOOT            0x80U

#define LSM6DSV16X_STATUS_XLDA           0x01U
#define LSM6DSV16X_STATUS_GDA            0x02U

/* Embedded-function registers (SFLP_ODR, EMB_FUNC_EN_A, EMB_FUNC_FIFO_EN_A) are
   only reachable while this bit is set; otherwise the same addresses mean
   something else in the main page and the writes silently go nowhere. */
#define LSM6DSV16X_FUNC_CFG_EMB_ACCESS   0x80U

#define LSM6DSV16X_EMB_FUNC_EN_A_SFLP_GAME      0x02U
#define LSM6DSV16X_EMB_FUNC_FIFO_EN_A_SFLP_GAME 0x02U

/* SFLP_GAME_ODR[2:0]: 15/30/60/120/240/480 Hz. 120 Hz leaves the 240 Hz
   sensor ODR two samples per fused output and keeps FIFO traffic light. */
#define LSM6DSV16X_SFLP_ODR_120HZ        0x03U

/* FIFO_MODE[2:0] = 110: stream/continuous. When the buffer fills the oldest
   words are dropped, so a host that stalls loses resolution but never wedges. */
#define LSM6DSV16X_FIFO_MODE_STREAM      0x06U

/* Each FIFO word is one tag byte plus six data bytes, read in one burst. */
#define LSM6DSV16X_FIFO_WORD_LEN         7U
#define LSM6DSV16X_FIFO_MAX_WORDS        4U

/* FIFO tag of the SFLP game rotation vector. */
#define LSM6DSV16X_FIFO_TAG_SFLP_GAME    0x13U

#define LSM6DSV16X_I2C_TIMEOUT_MS        100U
#define LSM6DSV16X_RESET_TIMEOUT_MS      100U

static I2C_HandleTypeDef *lsm6dsv16x_i2c;
static uint16_t lsm6dsv16x_device_address;

static HAL_StatusTypeDef LSM6DSV16X_ReadRegister(uint8_t reg, uint8_t *data,
                                                 uint16_t length)
{
  if ((lsm6dsv16x_i2c == NULL) || (lsm6dsv16x_device_address == 0U) ||
      (data == NULL) || (length == 0U))
  {
    return HAL_ERROR;
  }

  return HAL_I2C_Mem_Read(lsm6dsv16x_i2c, lsm6dsv16x_device_address, reg,
                          I2C_MEMADD_SIZE_8BIT, data, length,
                          LSM6DSV16X_I2C_TIMEOUT_MS);
}

static HAL_StatusTypeDef LSM6DSV16X_WriteRegister(uint8_t reg, uint8_t value)
{
  if ((lsm6dsv16x_i2c == NULL) || (lsm6dsv16x_device_address == 0U))
  {
    return HAL_ERROR;
  }

  return HAL_I2C_Mem_Write(lsm6dsv16x_i2c, lsm6dsv16x_device_address, reg,
                           I2C_MEMADD_SIZE_8BIT, &value, 1U,
                           LSM6DSV16X_I2C_TIMEOUT_MS);
}

static HAL_StatusTypeDef LSM6DSV16X_WaitWhileSet(uint8_t reg, uint8_t mask)
{
  uint32_t start_tick = HAL_GetTick();
  uint8_t value;

  do
  {
    if (LSM6DSV16X_ReadRegister(reg, &value, 1U) != HAL_OK)
    {
      return HAL_ERROR;
    }
    if ((value & mask) == 0U)
    {
      return HAL_OK;
    }
    HAL_Delay(1U);
  } while ((HAL_GetTick() - start_tick) < LSM6DSV16X_RESET_TIMEOUT_MS);

  return HAL_TIMEOUT;
}

static HAL_StatusTypeDef LSM6DSV16X_FindDevice(void)
{
  static const uint8_t addresses[] = {
    LSM6DSV16X_I2C_ADDRESS_LOW,
    LSM6DSV16X_I2C_ADDRESS_HIGH
  };
  uint8_t who_am_i;
  uint32_t index;

  for (index = 0U; index < (sizeof(addresses) / sizeof(addresses[0])); ++index)
  {
    lsm6dsv16x_device_address = (uint16_t)(addresses[index] << 1U);
    if ((HAL_I2C_IsDeviceReady(lsm6dsv16x_i2c, lsm6dsv16x_device_address,
                               2U, LSM6DSV16X_I2C_TIMEOUT_MS) == HAL_OK) &&
        (LSM6DSV16X_ReadRegister(LSM6DSV16X_REG_WHO_AM_I, &who_am_i, 1U) == HAL_OK) &&
        (who_am_i == LSM6DSV16X_WHO_AM_I_VALUE))
    {
      return HAL_OK;
    }
  }

  lsm6dsv16x_device_address = 0U;
  return HAL_ERROR;
}
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

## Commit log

2026-09-15 OptiDuck umbrella: board tutorial, scratch archive and submodule pins
    - README.md: what OptiDuck is, how the submodules fit together, and the
    two-step workflow for syncing a change (commit in the submodule, then bump
    the pointer here)
    - Radxa_ZERO_3W_...: full bring-up tutorial from flashing the SD card to
    installing the daemon software stack
    - _scratch_archive/: draft CAD, render output and captured logs
    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
    [_hd1910_tmp.stl, _xl330.stp]
2026-09-16 OptiDuck umbrella: re-pin microduck and OpenMicroDuck submodules to upstream
    Follow original authors directly (drops local sim336 forks):
    - joyandai/microduck -> pollen-robotics/microduck @ fead66b
    - OpenMicroDuck -> JoyandAI/OpenMicroDuck @ 21c5a19
    Local HD1910 work preserved on backup/* branches.
2026-09-19 OptiDuck v1.00: 整理为可发布的开源仓库形态
    目录重构：docs/（教程）、tools/urdf/（URDF/MJCF 工具链）、board/（板端运维）、
    app/（Android App）、training/（上游 RL 仓改动）、assets/（真实截图与渲染帧）。
    散落在根目录的教程、工具、脚本、截图全部归位。
    补齐开源配套：LICENSE（Apache-2.0）、NOTICE.md（分项署名；OpenMicroDuck 的
    CAD/图纸/文档为 CC-BY-NC-SA-4.0，不可商用）、.gitignore（排除大体积原始数据、
    本地 SDK/JDK、Android 构建产物与 local.properties）。
    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
    [ankle_left.STL, ankle_right.STL, base_link.STL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]
2026-09-19 README: 修正 App 章节并补移动端编译小节
    上一版 README 里 App 那节还停留在旧的四列截图表和错误的页签顺序（实际是 连接/状态/功能/终端）。本轮装进模拟器实测后按真实顺序重排截图，并补上 app/ 的编译步骤与产物路径提醒（Gradle 工程在 app/、模块也叫 app/，产物是 app/app/build/）。同时把 mermaid 图里的 boards/ 笔误改回 board/。
2026-09-19 Point microduck_rl at the HD1910 toolchain commit; drop scratch renders
    - microduck_rl: 982b8f8 -> 0100356 (Windows-capable policy viewer, --headless
    and --spawn postures, servo mesh-name fix, mass/inertia debug helpers).
    - remove _scratch_archive/renders (47 files, 9.5 MB): superseded model-view
    renders, HD1910 datasheet crops and draft screenshots, none referenced by
    the README or docs. The kept renders live under assets/renders/.
2026-10-01 board/app: 板端实时画面链路（MJPEG :8072 + App「画面」页）
    全程不经 mediad：board/report_video.py 用 GStreamer
    `v4l2src ! videorate ! videoconvert ! jpegenc ! appsink` 直接抓 /dev/video0，
    以 multipart/x-mixed-replace 推流（端口 8072），首包带 token（复用
    /home/radxa/robot_terminal_token），另有 /snapshot 单帧与 /stats 自检端点。
    流水线懒启动、无客户端 5 s 自动停 —— 所以「连接 / 断开」本身就是开关，默认关，
    不连时板上零占用（实测：无客户端 0.0% 单核；1 客户端推 640×480@15 约 16% 单核）。
    App 底部导航扩为 5 个页签（连接 / 状态 / 画面 / 功能 / 终端，2.1.0 -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
2026-10-01 tools: 台架标定与遥测工具入库；imu2uart 只收源码，产物与日志不入库
    tools/ 新增 6 个文件（都不是示例代码，是台架上实际在用的）：
    - ft_regs.py：FT-SCS 寄存器直读/直写。起因是 robot.relax 报 torque off、15 颗
    舵机全部 ACK，但关节掰不动 —— 绕开 robotd 直接读总线，15 颗的 reg40 实测全是 1，
    那条「已松扭矩」的结论是假的。
    - servo_config_gui.py / servo_progress.json：舵机逐个配置与进度。
    - bench_mirror.py：台架只读实时镜像（真机 15 颗 HD-1910 + IMU 映到浏览器 3D），
    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
    [servo_progress.json]
2026-10-01 docs: 补摄像头点亮记录；更新日志记 v1.01 / v1.02
    docs/internal 的零基础开发教程：摄像头一节从【等硬件】改为【现在能跑】。
    2026-09-22 已在本机点亮 IMX219（22-pin / 0.5 mm 直插，未用转接板）—— overlay
    启用后 probe 成功、/dev/media0 + /dev/video0~9 就位、连续抓流 45 帧 @ 29.96 fps。
    顺带更正三处容易踩的点：Radxa OS 上不用手工编辑 extlinux.conf（u-boot-update 会
    把 /boot/dtbo/ 下所有不带 .disabled 的 .dtbo 按字母序写进 fdtoverlays）；/boot/dtbo/
    下其实有三个 camera overlay（两个 IMX219 驱动层等价）；别只靠 dmesg | grep imx219
    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
2026-10-01 chore: 忽略 Keil 的调试 / 运行时配置目录
    imu2uart/MDK-ARM/DebugConfig/ 与 RTE/ 是 Keil 的本地用户配置，不入库。
    补上第 2 个提交里漏掉的两条规则。
2026-10-01 microduck_rl: 指向 HD-1910 供电基准与一致性修正
    子模块 develop 前进 3 个提交（0100356 -> ebad277）：
    - HD-1910: 2S supply basis, and the three missing USE_HD1910 branches
    供电基准从台架的 5.0 V 改到整机 2S（vin_range 6.5-8.2、vin_min 6.0、
    forcerange 0.97 -> 1.51 N.m），并补齐 GROUND_PICK / BACKLASH /
    WALK_BACKLASH 三处漏掉的 USE_HD1910 判断（含两个新导出的
    robot_openmicroduck_*_backlash.xml）。
    - sim: point the body server at the HD-1910 duck
    - velstand: make zero-command standing a first-class deliverable
2026-10-01 README: 校对到当前状态
    把仓库门面补到与已提交内容一致，不改正文其余部分：
    - 仓库结构表：`tools/urdf/` 扩写成 `tools/`（含 ft_regs.py / servo_config_gui.py /
    bench_mirror.py / robotd_telemetry_bridge.py 这几个台架工具）；新增 `imu2uart/` 行
    （并注明只入库自研源码，vendor 库与 Keil 产物可再生产）；`board/` 的说明补上「画面流」。
    - 大体积数据：补 `logs/` 一行（约 8 MB 台架原始数据，已进 .gitignore，不作为 Release 附件）。
    - 更新日志：新增 v1.03 —— 记 tools 的 6 个台架工具、imu2uart 只收源码、logs 入 ignore、
    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
2026-10-01 docs: 记录整机装配完成与策略首次上机（实拍照片 + 运行视频）
    整机装配完成，训练策略第一次在真整机上闭环跑起来。新增实拍素材：
    - assets/hardware/duck-assembled.jpg（整机外观，裸机状态）
    - assets/videos/duck-real-run.{gif,mp4}（720x1280 / 30fps / 6.5s，gif 为 README 内嵌压缩版）
    README 如实记录实测结论：起身策略跑了但没站稳，在抖动 / 翻倒过程中就切去
    执行走路，「起身 → 稳定 → 走路」的状态机衔接不成立；未通过项明确标注、
    不记为「会走了」，并把待排查方向（状态机切换判据、板上权重批次）留档。
    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
